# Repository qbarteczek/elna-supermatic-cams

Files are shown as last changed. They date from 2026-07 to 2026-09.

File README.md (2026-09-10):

# Generator krzywek Elna Supermatic / Elna Supermatic Cam Studio

*Dokument dwujęzyczny — polski niżej, English below. / Bilingual document — Polish first, English below.*

---

> [!TIP]
> ### 🌐 [URUCHOM GENERATOR KRZYWEK ONLINE (BEZ INSTALOWANIA PROGRAMÓW)](https://qbarteczek.github.io/elna-supermatic-cams/)
> **Dla każdego użytkownika maszyny:** wybierz dowolną krzywkę z katalogu 34 wzorów lub zaprojektuj własny ścieg w edytorze 18-krokowym, zobacz dysk w 3D oraz wirtualne przeszycie na tkaninie i pobierz gotowy plik `.stl` do druku 3D jednym kliknięciem (0.01 s)!
> 
> *English: [CLICK HERE TO LAUNCH THE 3D CAM GENERATOR IN BROWSER (NO SOFTWARE NEEDED)](https://qbarteczek.github.io/elna-supermatic-cams/)*

---

## PL

Otwarta biblioteka i interaktywny **generator krzywek ściegowych (cam discs)** do szwajcarskich maszyn **Elna Supermatic**, **Elna SU** i modeli pokrewnych. 

W odróżnieniu od maszyn ze stałymi bębnami wielościegowymi, Elna wykorzystuje pojedyncze, wymienne dyski montowane na obrotowym trzpieniu maszyny. Projekt łączy dokładne pomiary fizycznych dysków fabrycznych i skanów STL z parametrycznym generatorem 3D działającym w 100% w przeglądarce internetowej oraz w programie OpenSCAD.

### 🚀 Szybki start: 3 Sposoby korzystania z generatora

1. **🌐 Interaktywna aplikacja Webowa Online ([https://qbarteczek.github.io/elna-supermatic-cams/](https://qbarteczek.github.io/elna-supermatic-cams/)):**
   - **Podgląd 3D w czasie rzeczywistym (WebGL / Three.js):** natychmiastowe obracanie i oglądanie dysku z ząbkami wieńca, stożkowym otworem montażowym i gniazdem zabieraka.
   - **Bezpośrednie pobieranie STL:** klikasz *„💾 Pobierz STL do druku 3D”* i w 0.01 sekundy otrzymujesz szczelny (watertight / 2-manifold) plik `.stl` do wrzucenia do slicera (Bambu Studio, OrcaSlicer, PrusaSlicer, Cura).
   - **Wirtualne przeszycie na tkaninie:** podgląd nici na żywo dla 18 kroków pełnego obrotu dysku z animacją pracy maszyny.
   - **Katalog 34 krzywek fabrycznych:** 1-klikowe ładowanie profili od 01 do 34.
   - **Edytor 18-krokowy:** pełna swoboda tworzenia własnych ściegów z narzędziami generowania sinusoidy, schodków, zygzaka czy muszelki.
   - **Działanie offline:** wystarczy kliknąć dwukrotnie plik `Uruchom_Generator.bat` w głównym katalogu projektu.
2. **Panel okienkowy OpenSCAD Customizer GUI** ([`tools/openscad/elna_cam_generator.scad`](tools/openscad/elna_cam_generator.scad)): rozwijane menu wyboru krzywek 01–34 lub tryb Custom w oknie OpenSCAD (Window -> Customizer).
3. **Wiersz poleceń Python** ([`tools/generate_cam.py`](tools/generate_cam.py)): zautomatyzowane generowanie modeli `.scad` i profili `.json`.

Szczegółowa instrukcja obsługi: [`docs/GENERATOR.md`](docs/GENERATOR.md) (PL) oraz [`docs/GENERATOR.en.md`](docs/GENERATOR.en.md) (EN).

---

### ⚙️ Wymiary techniczne i pomiary nominalne

Dyski generowane są na podstawie ścisłych wymiarów nominalnych:
- **Średnica zewnętrzna:** 43.64 mm (promień maks. 21.82 mm)
- **Wysokość całkowita:** 7.31 mm (korpus 7.00 mm + oznaczenia 0.31 mm)
- **Wieniec roboczy:** wysokość 4.50 mm, promień bazowy 18.55 mm, promień maks. 21.82 mm
- **Skok krzywki (Throw):** 3.27 mm (przekłada się na szerokość ściegu 0–4 mm)
- **Otwór osi:** fi 16.50 mm (r=8.25 mm) z dolnym podtoczeniem fi 19.00 mm (h=1.5 mm) i stożkiem 1.5 mm
- **Gniazdo zabieraka napędowego:** szerokość 3.0 mm, długość 4.1 mm, głębokość 5.5 mm

---

### 📚 Pełny indeks 34 krzywek w repozytorium

| Numer | Nazwa ściegu | Status | Wieniec | Zastosowanie |
|:---:|:---|:---:|:---:|:---|
| **01** | Elastic multi-step | candidate | smooth | Ścieg elastyczny wielostopniowy |
| **02** | Serpentine | candidate | smooth | Serpentyna / płynna fala |
| **03** | Zigzag reference | reference STL/SCAD | stepped | Zygzak standardowy referencyjny |
| **04** | Long scallop | candidate | smooth | Długa muszelka ozdobna |
| **05** | Scallop | candidate | smooth | Klasyczna muszelka brzegowa |
| **06** | Wide zigzag | candidate | stepped | Zygzak szeroki dwustopniowy |
| **07** | Decorative zigzag | candidate | smooth | Zygzak ozdobny ząbkowany |
| **08** | Slanted bars | candidate | stepped | Paski skośne / jodełka |
| **09** | W stitch | candidate | stepped | Ścieg w kształcie litery W |
| **10** | Blind hem | candidate | stepped | Ścieg kryty do podszywania |
| **11** | Arrows | candidate | smooth | Strzałki geometryczne |
| **12** | Spindle | candidate | smooth | Wrzeciono / kropla satynowa |
| **13** | Source profile 13 | source-profile | smooth | Profil bazowy z projektu źródłowego |
| **14** | Loop wave | candidate | smooth | Pętle faliste |
| **15** | Triangle | candidate | stepped | Trójkąty ostre |
| **16** | Source profile 16 | source-profile | smooth | Profil bazowy z projektu źródłowego |
| **17** | Round pulses | candidate | stepped | Impulsy zaokrąglone |
| **18** | Deep scallop | candidate | smooth | Głęboka muszelka satynowa |
| **19** | Dense zigzag | candidate | stepped | Zygzak gęsty |
| **20** | Source profile 20 | source-profile | stepped | Profil bazowy z projektu źródłowego |
| **21** | Stair zigzag | candidate | smooth | Zygzak schodkowy |
| **22** | Small lobes | candidate | smooth | Drobne łuski |
| **23** | Sharp triangles | candidate | smooth | Trójkąty wyostrzone |
| **24** | Small scallop | candidate | smooth | Drobna muszelka |
| **25** | Large sine wave | candidate | smooth | Duża sinusoida |
| **26** | Wave variant | candidate | smooth | Wariant fali symetrycznej |
| **27** | Irregular pulse | candidate | stepped | Impuls nieregularny |
| **28** | Vertical ticks | candidate | stepped | Pionowe kreski / grzebyk |
| **29** | Comb alternate | candidate | smooth | Grzebyk naprzemienny |
| **30** | Uneven wave | candidate | smooth | Fala asymetryczna |
| **31** | Block sawtooth | candidate | stepped | Zęby piły blokowe |
| **32** | Slanted bars | candidate | smooth | Paski skośne gładkie |
| **33** | Source profile 33 | source-profile | smooth | Profil bazowy z projektu źródłowego |
| **34** | Extra decorative | candidate | smooth | Złożony ścieg dekoracyjny |

---

### 🖨️ Zalecenia dotyczące druku 3D (FDM)

- **Materiał:** **PETG** (zalecany ze względu na niski współczynnik tarcia i odporność na pękanie) lub **PLA / PLA+**.
- **Wysokość warstwy:** `0.12 mm` lub `0.16 mm` dla idealnie gładkiego profilu krzywki.
- **Wypełnienie / Ścianki:** 4–5 obrysów lub 100% wypełnienia (dysk musi być sztywny).
- **Pozycja na stole:** Płasko, spodem do stołu (brak podpór).

---

### 📁 Struktura projektu

```text
├── index.html                           # Główna aplikacja generatora online (GitHub Pages)
├── Uruchom_Generator.bat                # 1-klikowy launcher pod Windows
├── docs/
│   ├── GENERATOR.md                     # Instrukcja obsługi generatora (PL)
│   ├── GENERATOR.en.md                  # Generator user guide (EN)
│   ├── DIMENSIONS_FROM_UPLOADED_FILES.md# Raport z pomiarów referencyjnych
│   └── MEASURED_PARAMETRIC_INDEX.md     # Indeks krzywek parametrycznych
├── models/
│   ├── measured_parametric_single_v1/   # Gotowe modele OpenSCAD dla krzywek 01–34
│   │   ├── _elna_measured_common.scad   # Główna baza wymiarowa
│   │   ├── cam_01.scad ... cam_34.scad  # Pliki modeli
│   │   └── profiles/                    # Profile JSON dla wszystkich 34 krzywek
├── tools/
│   ├── build_index_html.py              # Skrypt kompilujący index.html z presetami
│   ├── generate_cam.py                  # Narzędzie CLI do generowania SCAD i JSON
│   ├── openscad/
│   │   └── elna_cam_generator.scad      # Generator OpenSCAD z panelem Customizer
│   └── generator/
│       └── index.html                   # Kopia aplikacji webowej do pracy offline
└── LICENSE                              # Licencja GPL-3.0
```

---

## EN

Open library and interactive **stitch cam disc generator** for the legendary Swiss sewing machines **Elna Supermatic**, **Elna SU**, and related models.

### 🌐 [LAUNCH 3D CAM GENERATOR IN BROWSER](https://qbarteczek.github.io/elna-supermatic-cams/)

- **No installation needed:** Runs in your browser with real-time WebGL 3D preview and instant 0.01 s binary STL download.
- **Full library of 34 factory cam profiles:** 1-click loading with live fabric stitch simulation.
- **18-Step Custom Designer:** Create completely custom stitch designs.
- **OpenSCAD GUI Customizer:** Available in `tools/openscad/elna_cam_generator.scad`.
- **3D Print Ready:** Watertight 2-manifold STL models tailored for PETG/PLA printing with zero supports.

Read the complete English guide in [`docs/GENERATOR.en.md`](docs/GENERATOR.en.md).

---

## Licencja / License

Projekt objęty licencją **GPL-3.0-or-later**.
Zachowaj informacje o autorach kodu bazowego i projektów źródłowych (ln-komandur/elna-cam-discs).

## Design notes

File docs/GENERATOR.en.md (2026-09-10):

# Elna Supermatic Cam Generator User Guide

This repository features a built-in, versatile system for generating factory and custom stitch cam discs for the iconic Swiss sewing machines **Elna Supermatic**, **Elna SU**, and related models.

The generator includes a full catalog of **34 pre-configured cam profiles** (utility stitches, elastic stretch stitches, decorative scallops, waves, and geometric patterns) and an interactive 18-step designer for creating brand new stitches.

---

## 🌐 In-Browser Online Generator (Recommended!)

> [!TIP]
> **No installation required (no OpenSCAD, Python, or compiler needed)!**
> Access the generator directly in your browser:
> 👉 **[https://qbarteczek.github.io/elna-supermatic-cams/](https://qbarteczek.github.io/elna-supermatic-cams/)**

The application runs 100% locally in your web browser (desktop, tablet, or smartphone) and produces a production-ready, watertight binary `.stl` file in a fraction of a second (0.01 s).

---

## 3 Ways to Use the Generator

### Method 1: Web App Online / Offline (Easiest for Everyone)

1. **How to Launch:**
   * **Online (recommended):** Visit [https://qbarteczek.github.io/elna-supermatic-cams/](https://qbarteczek.github.io/elna-supermatic-cams/)
   * **Offline on PC:** Double click `Uruchom_Generator.bat` in the project root folder (or open `index.html` in any modern web browser).
2. **Features:**
   * **Real-Time 3D Cam Disc Viewer (WebGL / Three.js):** rotate, zoom, and inspect the real cam disc geometry with lower functional lobe, central bore, counterbore, driving pin slot, and embossed top markings.
   * **Virtual Fabric Seam Simulation:** live simulation showing what stitch pattern is formed on fabric over the 18 steps of the cam rotation. Click *„▶ Start Machine”* to watch the animated sewing action!
   * **Catalog of 34 Cams:** 1-click loading of any factory cam (01 through 34) with live search and wave previews.
   * **18-Step Profile Designer:** interactive height sliders for each needle position (`L`, `CL`, `C`, `CR`, `R` or continuous 0.0 – 3.0), wave generator tools (sine, zigzag, stairs, blind hem, invert).
   * **Custom Markings:** set custom cam numbers (e.g. `03`, `42`, `MY`) embossed in 3D on the disc surface.
3. **Download 3D Print File:**
   * Click the green button **„💾 Download STL for 3D Printing”** – in 0.01 s you get a watertight (2-manifold) `elna_cam_XX.stl` file ready for slicing in Bambu Studio, OrcaSlicer, PrusaSlicer, or Cura.
   * You can also download the OpenSCAD `.scad` code or export/import `.json` profiles.

---

### Method 2: In OpenSCAD (Customizer GUI)

For users who prefer working inside OpenSCAD:
1. Install [OpenSCAD](https://openscad.org/) (version 2021.01+).
2. Open [`tools/openscad/elna_cam_generator.scad`](../tools/openscad/elna_cam_generator.scad).
3. Enable the GUI parameter panel: **Window -> Customizer** (or uncheck *Hide Customizer*).
4. Select a preset from `PRESET` (`01` to `34`) or select `CUSTOM` to adjust the 18 step sliders.
5. Press **F5** (preview) or **F6** (render), then **F7** (Export as STL).

---

### Method 3: Python Command Line (`tools/generate_cam.py`)

CLI script for automated generation of `.scad` files and `.json` profiles:
```bash
# Generate a SCAD model from 18 values:
python tools/generate_cam.py --cam 03 --values 0,3,0,3,0,3,0,3,0,3,0,3,0,3,0,3,0,3 --mode stepped --out models/generated/cam_03.scad

# Generate from an existing JSON profile:
python tools/generate_cam.py --profile models/measured_parametric_single_v1/profiles/cam_10_profile.json --out output.scad
```

---

## Cam Catalog Overview (01–34)

| Cam | Stitch Name | Status | Cam Surface | Application |
|:---:|:---|:---:|:---:|:---|
| **01** | Elastic multi-step | candidate | smooth | Multi-step stretch stitch |
| **02** | Serpentine | candidate | smooth | Smooth wave / serpentine |
| **03** | Zigzag reference | uploaded-stl/reference | stepped | Standard reference zigzag |
| **04** | Long scallop | candidate | smooth | Extended decorative scallop |
| **05** | Scallop | candidate | smooth | Classic edge scallop |
| **06** | Wide zigzag | candidate | stepped | 2-step wide zigzag |
| **07** | Decorative zigzag | candidate | smooth | Saw-tooth decorative zigzag |
| **08** | Slanted bars | candidate | stepped | Slanted bar chevron |
| **09** | W stitch | candidate | stepped | W-shaped stitch |
| **10** | Blind hem | candidate | stepped | Blind hem hemming stitch |
| **11** | Arrows | candidate | smooth | Geometric arrowheads |
| **12** | Spindle | candidate | smooth | Satin spindle / teardrop |
| **13** | Source profile 13 | source-profile | smooth | Profile from base project |
| **14** | Loop wave | candidate | smooth | Looped waves |
| **15** | Triangle | candidate | stepped | Sharp triangles |
| **16** | Source profile 16 | source-profile | smooth | Profile from base project |
| **17** | Round pulses | candidate | stepped | Rounded pulse waves |
| **18** | Deep scallop | candidate | smooth | Deep satin scallop |
| **19** | Dense zigzag | candidate | stepped | Dense zigzag |
| **20** | Source profile 20 | source-profile | stepped | Profile from base project |
| **21** | Stair zigzag | candidate | smooth | Stepped staircase zigzag |
| **22** | Small lobes | candidate | smooth | Small rounded lobes |
| **23** | Sharp triangles | candidate | smooth | Sharpened triangle pattern |
| **24** | Small scallop | candidate | smooth | Fine edge scallop |
| **25** | Large sine wave | candidate | smooth | Large amplitude sine wave |
| **26** | Wave variant | candidate | smooth | Symmetric wave variation |
| **27** | Irregular pulse | candidate | stepped | Asymmetric pulse sequence |
| **28** | Vertical ticks | candidate | stepped | Vertical comb ticks |
| **29** | Comb alternate | candidate | smooth | Alternating comb pattern |
| **30** | Uneven wave | candidate | smooth | Asymmetric wave |
| **31** | Block sawtooth | candidate | stepped | Block sawtooth |
| **32** | Slanted bars | candidate | smooth | Smooth slanted bars |
| **33** | Source profile 33 | source-profile | smooth | Profile from base project |
| **34** | Extra decorative | candidate | smooth | Complex decorative stitch |

---

## ⚙️ Technical Specifications & Dimensions

All models are built upon measured dimensions from physical original cam discs and high-precision reference STL scans:

| Feature | Nominal Value | Machine Function |
|---|:---:|---|
| **Outer Diameter ($D_{max}$)** | **43.64 mm** | Clearance in cam compartment |
| **Total Height ($H_{total}$)** | **7.31 mm** | Main body (7.0 mm) + embossed badges (0.31 mm) |
| **Base Cam Radius ($R_{base}$)** | **18.55 mm** | Far-left needle position (throw = 0 mm) |
| **Max Cam Radius ($R_{max}$)** | **21.82 mm** | Far-right needle position (throw = 4 mm) |
| **Functional Lobe Height ($H_{lobe}$)** | **4.50 mm** | Lower portion engaging cam follower |
| **Cam Throw** | **3.27 mm** | Needle bar lever deflection range |
| **Shaft Bore Diameter ($D_{hole}$)** | **16.50 mm** | Spindle mount fit ($r = 8.25$ mm) |
| **Lower Counterbore Diameter ($D_{counterbore}$)** | **19.00 mm** | Spindle shoulder recess ($r = 9.50$ mm, $h = 1.5$ mm) |
| **Conical Lead-in ($H_{cone}$)** | **1.50 mm** | Tapered transition from 19 mm to 16.5 mm |
| **Drive Pin Slot** | **3.0 × 4.1 mm** | Locating slot for driving pin ($d = 5.5$ mm) |

---

## 🖨️ 3D Printing Recommendations (FDM)

1. **Filament Choice:**
   * **PETG (Recommended):** High wear resistance against metal cam followers, good flexibility, non-brittle.
   * **PLA / PLA+:** Excellent dimensional fidelity and stiffness, fine for domestic stitching.
   * **ABS / ASA / Nylon:** Optional for advanced users.
2. **Slicer Settings:**
   * **Layer Height:** `0.12 mm` or `0.16 mm` for smooth cam profiles without layer stepping.
   * **Perimeters / Walls:** `4` to `5` loops.
   * **Infill:** `40%–100%` (rigid disc prevents deflection under follower spring pressure).
   * **Orientation:** Flat on build plate, bottom face down.
   * **Supports:** **None** – designed to print 100% support-free.

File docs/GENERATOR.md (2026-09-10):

# Instrukcja obsługi generatora krzywek Elna Supermatic

Projekt zawiera wbudowany, uniwersalny system generowania własnych oraz fabrycznych dysków ściegowych (krzywek wymiennych) do kultowych szwajcarskich maszyn do szycia **Elna Supermatic**, **Elna SU** i modeli pokrewnych.

Dostępny jest pełny katalog **34 gotowych profili krzywek** (ściegi użytkowe, elastyczne, dekoracyjne muszelki, fale i wzory geometryczne) oraz możliwość projektowania zupełnie nowych, autorskich ściegów w edytorze 18-krokowym.

---

## 🌐 Generator Online w Przeglądarce (Zalecany dla każdego użytkownika!)

> [!TIP]
> **Nie musisz instalować żadnego oprogramowania (w tym OpenSCAD ani Pythona)!**
> Wejdź bezpośrednio na stronę generatora:
> 👉 **[https://qbarteczek.github.io/elna-supermatic-cams/](https://qbarteczek.github.io/elna-supermatic-cams/)**

Aplikacja działa w 100% w przeglądarce internetowej (na komputerze, tablecie i smartfonie) i umożliwia wygenerowanie oraz natychmiastowe pobranie gotowego pliku `.stl` do druku 3D w ułamku sekundy (0.01 s).

---

## 3 Sposoby korzystania z generatora

### Sposób 1: Aplikacja Webowa Online / Lokalna (Najwygodniejszy dla każdego!)

1. **Uruchomienie:**
   * **Online (zalecane):** Otwórz [https://qbarteczek.github.io/elna-supermatic-cams/](https://qbarteczek.github.io/elna-supermatic-cams/)
   * **Lokalnie na komputerze (bez internetu):** Kliknij dwukrotnie plik `Uruchom_Generator.bat` w głównym katalogu projektu (lub po prostu otwórz plik `index.html` w ulubionej przeglądarce).
2. **Możliwości studia projektowego:**
   * **Interaktywny podgląd 3D dysku (WebGL / Three.js):** obracaj myszką, przybliżaj i oglądaj rzeczywisty dysk krzywki z wieńcem funkcyjnym, stożkowym otworem montażowym, wpustem zabieraka i sygnaturami górnymi.
   * **Wirtualna symulacja ściegu na tkaninie:** dynamiczny podgląd przeszycia nici na materiale dla 18 kroków pełnego obrotu dysku. Przycisk *„▶ Uruchom maszynę”* uruchamia realistyczną animację pracy igły i posuwu materiału.
   * **Katalog 34 krzywek Elna:** błyskawiczny wybór fabrycznych dysków (od 01 do 34) z podglądem fali i wyszukiwarką.
   * **Edytor 18-krokowy:** interaktywne słupki z regulacją odchylenia igły (pozycje `L`, `CL`, `C`, `CR`, `R` lub płynne wartości 0.0 – 3.0), narzędzia generowania fal (sinusoida, zygzak, schodki, trójskok, ścieg kryty, inwersja).
   * **Dostosowanie oznaczeń:** wpisz własny numer dysku wytłaczany na tarczy (np. `03`, `42`, `MY`) oraz wybierz rodzaj piktogramu.
3. **Pobranie pliku do druku 3D:**
   * Kliknij zielony przycisk **„💾 Pobierz STL do druku 3D”** – w ułamku sekundy otrzymujesz gotowy, w 100% szczelny (watertight / 2-manifold) plik `elna_cam_XX.stl`, który możesz bezpośrednio otworzyć w Bambu Studio, OrcaSlicer, PrusaSlicer czy Cura!
   * Możesz także pobrać kod źródłowy `.scad` lub wyeksportować/zaimportować profil `.json`.

---

### Sposób 2: W programie OpenSCAD (Panel Customizer GUI)

Dla użytkowników preferujących pracę bezpośrednio w programie OpenSCAD:
1. Zainstaluj darmowy program [OpenSCAD](https://openscad.org/) (wersja 2021.01 lub nowsza).
2. Otwórz plik [`tools/openscad/elna_cam_generator.scad`](../tools/openscad/elna_cam_generator.scad).
3. W górnym menu OpenSCAD włącz panel parametrów: **Window -> Customizer** (lub odznacz *Hide Customizer*).
4. Wybierz gotową krzywkę z listy `PRESET` (`01` do `34`) lub wybierz `CUSTOM` i ustaw własne wartości 18 kroków za pomocą suwaków.
5. Wciśnij klawisz **F5** (szybki podgląd) lub **F6** (pełny render), a po zakończeniu obliczeń **F7** (Export as STL).

---

### Sposób 3: Wiersz poleceń Python (`tools/generate_cam.py`)

Skrypt CLI do zautomatyzowanego generowania modeli `.scad` i profili `.json`:
```bash
# Wygenerowanie modelu SCAD z zadanymi 18 wartościami:
python tools/generate_cam.py --cam 03 --values 0,3,0,3,0,3,0,3,0,3,0,3,0,3,0,3,0,3 --mode stepped --out models/generated/cam_03.scad

# Wygenerowanie modelu na podstawie istniejącego pliku JSON profilu:
python tools/generate_cam.py --profile models/measured_parametric_single_v1/profiles/cam_10_profile.json --out output.scad
```

---

## Pełny wykaz profili krzywek w katalogu (01–34)

| Numer | Nazwa ściegu | Status | Typ wieńca | Zastosowanie |
|:---:|:---|:---:|:---:|:---|
| **01** | Elastic multi-step | candidate | smooth | Ścieg elastyczny wielostopniowy |
| **02** | Serpentine | candidate | smooth | Serpentyna / płynna fala |
| **03** | Zigzag reference | uploaded-stl/reference | stepped | Zygzak standardowy referencyjny |
| **04** | Long scallop | candidate | smooth | Długa muszelka ozdobna |
| **05** | Scallop | candidate | smooth | Klasyczna muszelka brzegowa |
| **06** | Wide zigzag | candidate | stepped | Zygzak szeroki dwustopniowy |
| **07** | Decorative zigzag | candidate | smooth | Zygzak ozdobny ząbkowany |
| **08** | Slanted bars | candidate | stepped | Paski skośne / jodełka |
| **09** | W stitch | candidate | stepped | Ścieg w kształcie litery W |
| **10** | Blind hem | candidate | stepped | Ścieg kryty do podszywania |
| **11** | Arrows | candidate | smooth | Strzałki geometryczne |
| **12** | Spindle | candidate | smooth | Wrzeciono / kropla satynowa |
| **13** | Source profile 13 | source-profile | smooth | Profil bazowy z projektu źródłowego |
| **14** | Loop wave | candidate | smooth | Pętle faliste |
| **15** | Triangle | candidate | stepped | Trójkąty ostre |
| **16** | Source profile 16 | source-profile | smooth | Profil bazowy z projektu źródłowego |
| **17** | Round pulses | candidate | stepped | Impulsy zaokrąglone |
| **18** | Deep scallop | candidate | smooth | Głęboka muszelka satynowa |
| **19** | Dense zigzag | candidate | stepped | Zygzak gęsty |
| **20** | Source profile 20 | source-profile | stepped | Profil bazowy z projektu źródłowego |
| **21** | Stair zigzag | candidate | smooth | Zygzak schodkowy |
| **22** | Small lobes | candidate | smooth | Drobne łuski |
| **23** | Sharp triangles | candidate | smooth | Trójkąty wyostrzone |
| **24** | Small scallop | candidate | smooth | Drobna muszelka |
| **25** | Large sine wave | candidate | smooth | Duża sinusoida |
| **26** | Wave variant | candidate | smooth | Wariant fali symetrycznej |
| **27** | Irregular pulse | candidate | stepped | Impuls nieregularny |
| **28** | Vertical ticks | candidate | stepped | Pionowe kreski / grzebyk |
| **29** | Comb alternate | candidate | smooth | Grzebyk naprzemienny |
| **30** | Uneven wave | candidate | smooth | Fala asymetryczna |
| **31** | Block sawtooth | candidate | stepped | Zęby piły blokowe |
| **32** | Slanted bars | candidate | smooth | Paski skośne gładkie |
| **33** | Source profile 33 | source-profile | smooth | Profil bazowy z projektu źródłowego |
| **34** | Extra decorative | candidate | smooth | Złożony ścieg dekoracyjny |

---

## ⚙️ Wymiary techniczne dysku Elna Supermatic

Wszystkie modele w generatorze bazują na dokładnych pomiarach oryginalnych dysków i referencyjnych skanów STL:

| Parametr konstrukcyjny | Wartość nominalna | Znaczenie w maszynie |
|---|:---:|---|
| **Średnica zewnętrzna ($D_{max}$)** | **43.64 mm** | Maksymalny gabaryt w gnieździe krzywek |
| **Wysokość całkowita ($H_{total}$)** | **7.31 mm** | Grubość korpusu (7.0 mm) + oznaczenia (0.31 mm) |
| **Promień bazowy wieńca ($R_{base}$)** | **18.55 mm** | Skrajna lewa pozycja igły (rzut = 0 mm) |
| **Promień maksymalny wieńca ($R_{max}$)** | **21.82 mm** | Skrajna prawa pozycja igły (rzut = 4 mm) |
| **Wysokość wieńca roboczego ($H_{lobe}$)** | **4.50 mm** | Dolna część współpracująca z popychaczem igielnicy |
| **Skok krzywki (Throw)** | **3.27 mm** | Zakres ruchu dźwigni igielnicy |
| **Średnica otworu osi ($D_{hole}$)** | **16.50 mm** | Otwór pasowany na trzpień napędowy (r=8.25 mm) |
| **Średnica dolnego podtoczenia ($D_{counterbore}$)** | **19.00 mm** | Pogłębienie na kołnierz osi (r=9.50 mm, h=1.5 mm) |
| **Stożek wprowadzający ($H_{cone}$)** | **1.50 mm** | Przejście stożkowe r=9.5 -> r=8.25 mm |
| **Wymiary gniazda zabieraka** | **3.0 × 4.1 mm** | Wpust na kołek napędowy (głębokość 5.5 mm) |

---

## 🖨️ Wskazówki dotyczące druku 3D (FDM)

1. **Materiał:**
   * **PETG (Zalecany):** Zapewnia doskonałą odporność na ścieranie przy tarciu metalowego popychacza, elastyczność i brak kruchości.
   * **PLA / PLA+:** Bardzo dobra dokładność wymiarowa i sztywność, odpowiednia do domowych zastosowań.
   * **ABS / ASA / Nylon:** Opcjonalnie dla zaawansowanych użytkowników.
2. **Ustawienia slicera:**
   * **Wysokość warstwy:** `0.12 mm` lub `0.16 mm` (zapewnia gładką krawędź krzywki bez schodkowania warstw).
   * **Obrysy (Perimeters / Walls):** `4` do `5` obrysów.
   * **Wypełnienie (Infill):** `40%–100%` (krzywka powinna być sztywna i solidna).
   * **Orientacja na stole:** Płasko, podstawą (dolną stroną z podtoczeniem) do stołu roboczego.
   * **Podpory:** **Brak** – model został zaprojektowany w sposób samonośny bez potrzeby stosowania podpór.
3. **Przygotowanie po wydruku:**
   * Oczyść ewentualne nitki (stringing) i sprawdź suwmiarką otwór centralny (16.5 mm). W razie potrzeby delikatnie przeszlifuj papierem ściernym gradacji 400–600 krawędź roboczą wieńca, aby zapewnić aksamitną pracę igielnicy.

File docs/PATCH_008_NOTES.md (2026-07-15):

# Patch 008 — measured parametric base

> **Note:** This document is kept for historical reference.
> The current project status and design rules are described in the main [README.md](../README.md).

---

This patch fixes the earlier mistake: it does not try to edit the frozen mesh SCAD.

Instead it builds a clean parametric OpenSCAD base using the dimensions read from the
uploaded STL/SCAD files.

## Rule

Preserve:
- measured outer size,
- total height,
- upper round body,
- central hole,
- lower counterbore/cone,
- transport slot,
- top style layout.

Change only:
- lower functional cam edge,
- number,
- stitch pictogram.

## Folder

```text
models/measured_parametric_single_v1/
```

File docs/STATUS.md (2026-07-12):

# Project status

## Stable base

The current stable direction is:

```text
models/measured_parametric_single_v1/
```

This base is dimensioned from the uploaded STL/SCAD reference files.

## Reliability levels

### `uploaded-stl/scad-reference`

The cam is based on the uploaded STL/SCAD reference.

Currently:

- 03

### `source-profile`

The cam uses a known 18-position OpenSCAD profile.

Currently:

- 13
- 16
- 20
- 33

### `candidate`

The cam uses the measured base, but the functional outer profile is not yet verified from a physical disc.

Currently:

- remaining generated cams 01–34

## Do not treat candidates as final

Candidate profiles are useful for visual comparison and early development, but should not be sold or described as factory-accurate until verified.

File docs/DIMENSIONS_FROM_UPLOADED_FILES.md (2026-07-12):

# Dimensions read from uploaded STL/SCAD

## Parsed STL / SCAD measurements

- SCAD object1Min: `[45.388, 55.498, 0.0]`
- SCAD object1Max: `[89.02, 97.731, 7.308]`
- SCAD extents: `[43.632, 42.233, 7.308] mm`

### ElnaSupermaticZizagCamWhole.stl

- vertices: `40482`
- min: `[45.388, 55.498, 0.0]`
- max: `[89.02, 97.731, 7.308]`
- extents: `[43.632, 42.233, 7.308]` mm
- bbox center: `[67.204, 76.615, 3.654]`
- max radius from bbox center: `22.043 mm`

### ElnaSupermaticZizagCam3NoBottomRing.stl

- vertices: `27402`
- min: `[50.725, 8.941, 0.0]`
- max: `[94.361, 51.742, 6.048]`
- extents: `[43.636, 42.801, 6.048]` mm
- bbox center: `[72.543, 30.342, 3.024]`
- max radius from bbox center: `22.044 mm`

## Dimensions used in patch 008

| Parameter | Value |
|---|---:|
| `overall_diameter_mm` | 43.640 mm |
| `overall_radius_mm` | 21.820 mm |
| `total_height_mm` | 7.308 mm |
| `body_top_height_mm` | 6.999 mm |
| `label_height_mm` | 0.309 mm |
| `lower_cam_lobe_height_mm` | 4.499 mm |
| `upper_round_body_radius_mm` | 18.550 mm |
| `functional_lobe_min_radius_mm` | 18.550 mm |
| `functional_lobe_max_radius_mm` | 21.820 mm |
| `functional_lobe_throw_mm` | 3.270 mm |
| `center_hole_radius_mm` | 8.250 mm |
| `center_counterbore_radius_mm` | 9.500 mm |
| `center_counterbore_height_mm` | 1.500 mm |
| `center_cone_height_mm` | 1.500 mm |
| `transport_slot_width_mm` | 3.000 mm |
| `transport_slot_length_mm` | 4.100 mm |
| `transport_slot_depth_mm` | 5.500 mm |
| `transport_slot_gap_from_counterbore_mm` | 1.000 mm |

## Design rule used

The model preserves fixed dimensions and holes. Only these elements are variable:
- lower functional cam edge,
- number,
- stitch pictogram.

## Important

The candidate cams preserve the correct measured base and style, but their functional edge is not factory-verified until compared with a real top-down photo or STL scan.

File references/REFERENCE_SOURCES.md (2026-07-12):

# Reference sources

This patch primarily uses the user's uploaded files:
- ElnaSupermaticZizagCamWhole.stl
- ElnaSupermaticZizagCam3NoBottomRing.stl
- ElnaSupermaticZizagCamWhole.scad

Public references are used only for numbering and classification, not for claiming exact factory cam geometry.

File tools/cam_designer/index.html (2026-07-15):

🧵

# Elna Supermatic Cam Designer

Draw a stitch pattern → generate OpenSCAD cam disc

18 positions · 20° each GPL-3.0

## Stitch Pattern Editor

Click or drag to draw · Y = needle lateral position

✏️ Draw 〰️ Smooth Presets: Zigzag Straight Step Wave Satin Clear

3.0 2.0 1.0 0.0

0°40°80°120° 160°200°240°280° 320°360°

## Cam Profile Preview

Min radius

18.6mm

Max radius

21.8mm

Throw

3.3mm

Positions

18

## Stitch Pictogram Editor

Top disc icon (raised line)

Draw the stitch symbol that appears embossed on top of the cam disc.

✏️ Draw line 🧹 Erase 🗑️ Clear all ✨ Auto from stitch

Points snap to grid.
The line will be extruded 0.31mm
above the disc surface.

## Export

Cam number

Cam name

SCAD Type

Assembly Body Ring

⬇ JSON ⬇ SCAD ⬇ Both files

✓ Files downloaded!

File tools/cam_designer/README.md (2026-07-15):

# Elna Cam Designer

A browser-based tool for designing Elna Supermatic cam discs by drawing stitch patterns.

## How to use

### Online (GitHub Pages)
Open: **https://qbarteczek.github.io/elna-supermatic-cams/**

### Locally
Just open `index.html` in any modern browser — no installation, no server needed.

## Features

- **Stitch editor** — draw the needle position over 18 cam positions (0–360°)
  - Draw mode: click/drag to set exact values
  - Smooth mode: brush that blends neighbours
  - Presets: Zigzag, Straight, Step, Wave, Satin
- **Live cam preview** — SVG cam profile updates in real time
- **Pictogram editor** — draw the stitch icon that appears on top of the disc
  - Draw/erase tools
  - "Auto from stitch" — generates icon automatically from the stitch pattern
- **Export**
  - `cam_XX_profile.json` — profile data file for the repository
  - `cam_XX.scad` — ready-to-render OpenSCAD file (includes `_elna_measured_common.scad`)

## Value mapping

| Profile value | Needle position | Cam radius |
|---|---|---|
| `0.0` | Centre | 18.55 mm |
| `1.5` | Half-width | 20.19 mm |
| `3.0` | Full width | 21.82 mm |

18 positions × 20° each = one full stitch cycle (360°).

## Output files

After export, place the files in:

```
models/measured_parametric_single_v1/profiles/cam_XX_profile.json
models/measured_parametric_single_v1/cam_XX.scad
```

Then open `cam_XX.scad` in OpenSCAD and press **F6** to render.

> ⚠️ Exported cams have status `candidate` — always verify physically before use in a machine.

## License

GPL-3.0-or-later.

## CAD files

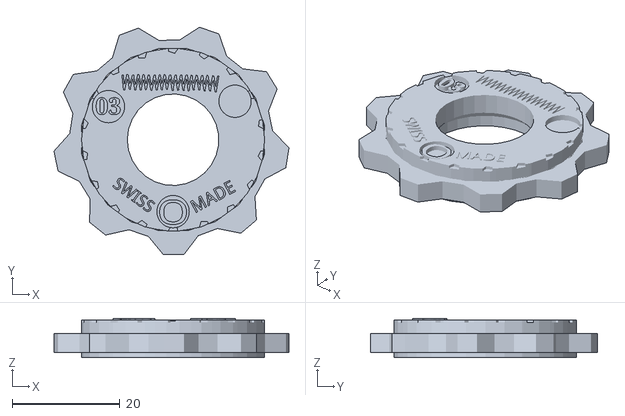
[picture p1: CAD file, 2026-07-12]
models/measured_parametric_single_v1/ElnaSupermaticZizagCamWhole.stl
43.6 x 42.2 x 7.31

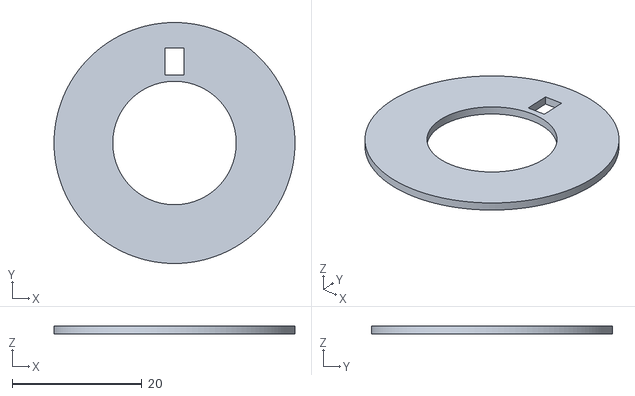
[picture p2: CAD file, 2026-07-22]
stls/universal_ring.stl
37.1 x 37.1 x 1.20

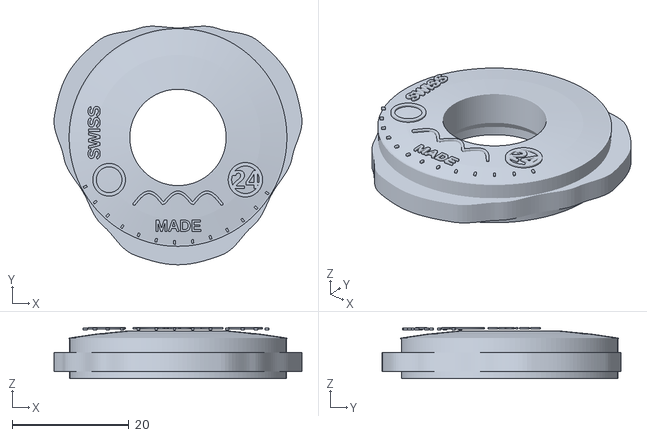
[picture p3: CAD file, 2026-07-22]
stls/cam_24_body.stl
42.5 x 40.9 x 8.81

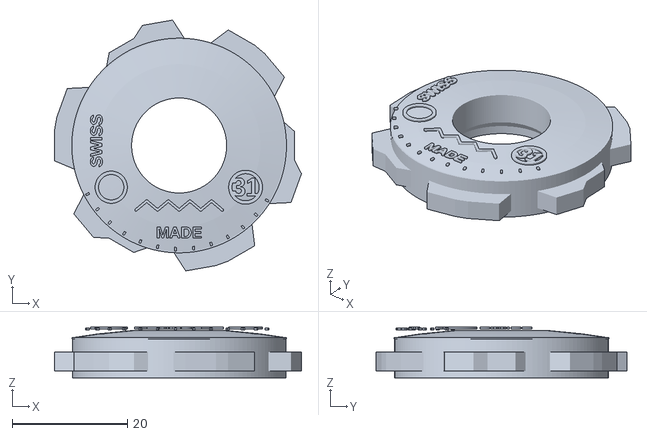
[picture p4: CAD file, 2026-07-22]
stls/cam_31_body.stl
42.9 x 43.6 x 8.81

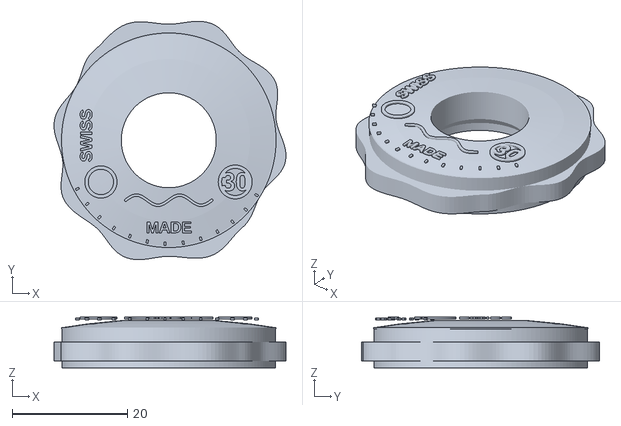
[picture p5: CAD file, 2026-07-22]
stls/cam_30_body.stl
40.3 x 41.4 x 8.81

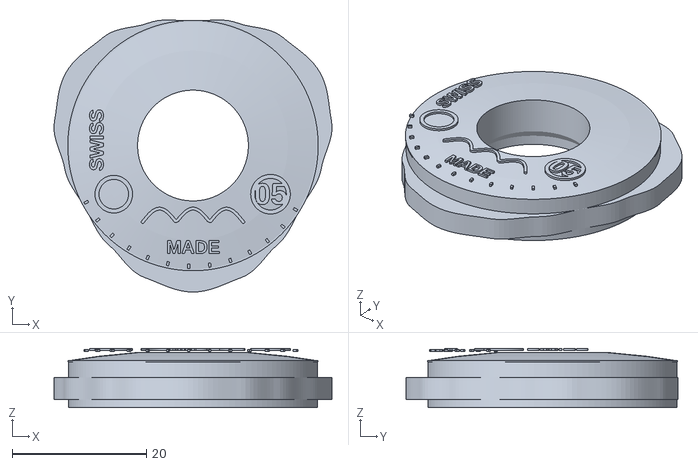
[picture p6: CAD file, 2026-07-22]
stls/cam_05_body.stl
41.4 x 40.5 x 8.81

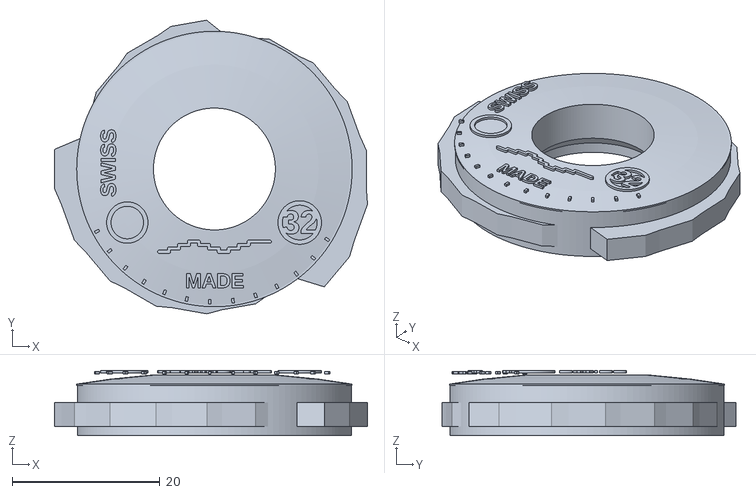
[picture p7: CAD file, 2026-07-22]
stls/cam_32_body.stl
42.4 x 39.8 x 8.81

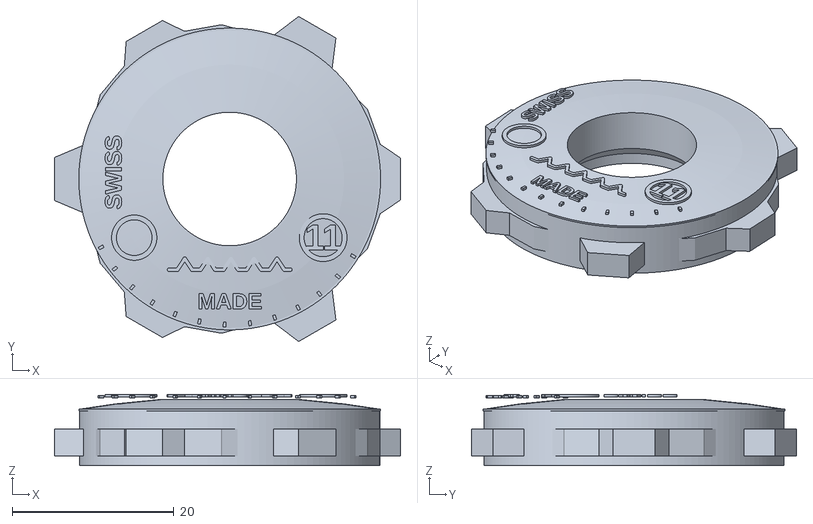
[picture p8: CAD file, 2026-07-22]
stls/cam_11_body.stl
42.8 x 40.2 x 8.81

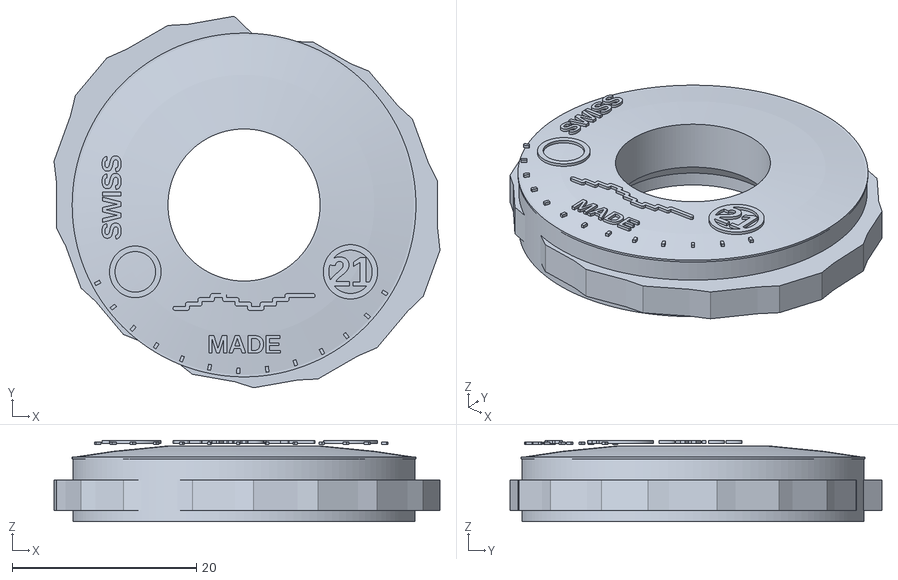
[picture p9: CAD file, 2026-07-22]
stls/cam_21_body.stl
41.9 x 40.3 x 8.81

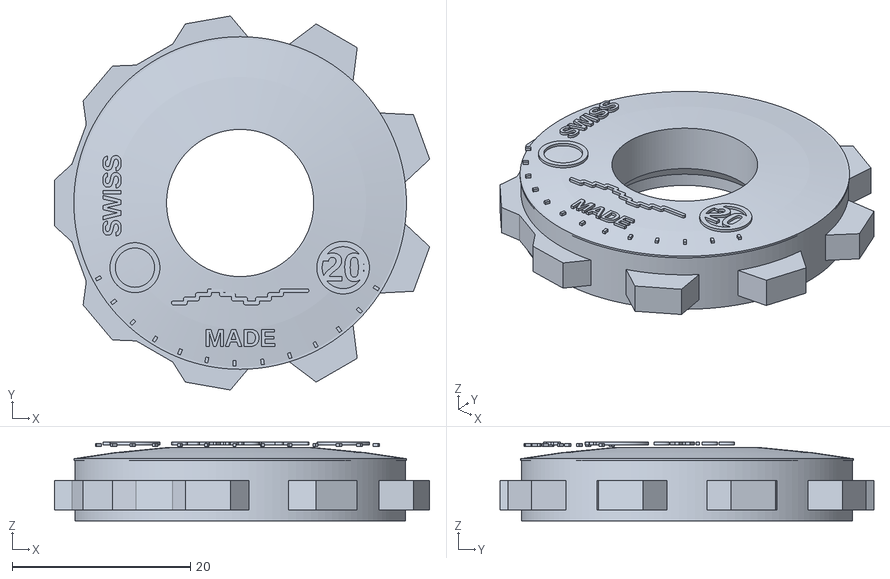
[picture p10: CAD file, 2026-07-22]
stls/cam_20_body.stl
42.1 x 41.9 x 8.81

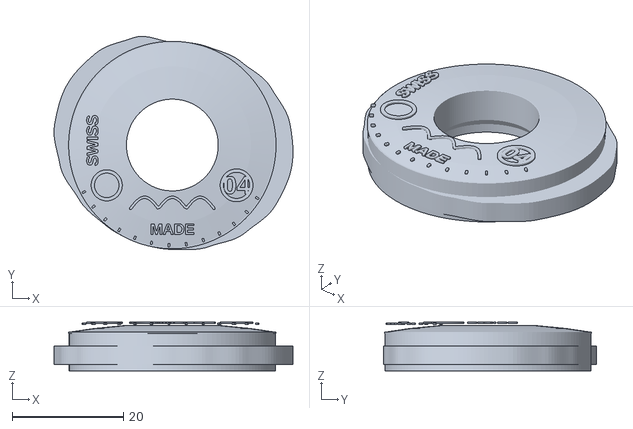
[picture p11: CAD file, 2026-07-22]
stls/cam_04_body.stl
43.0 x 38.3 x 8.81

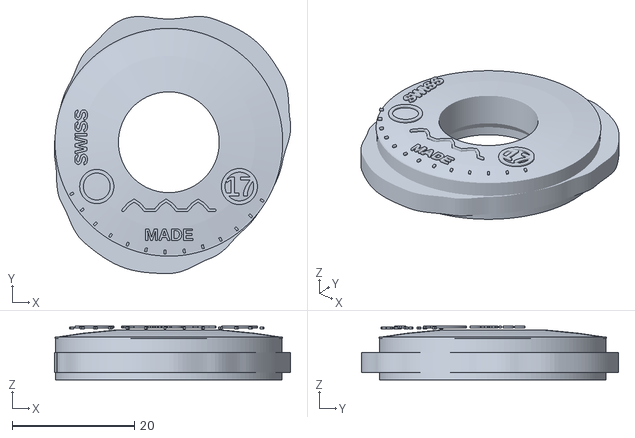
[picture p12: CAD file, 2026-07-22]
stls/cam_17_body.stl
38.7 x 42.1 x 8.81

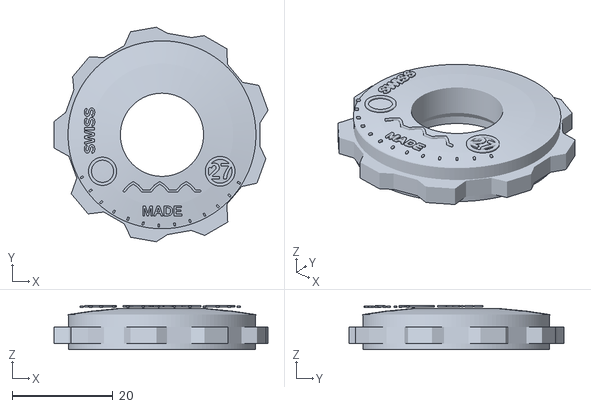
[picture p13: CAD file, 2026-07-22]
stls/cam_27_body.stl
42.5 x 42.6 x 8.81

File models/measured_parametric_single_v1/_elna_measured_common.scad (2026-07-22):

/*
  Elna Supermatic single cam — measured parametric base v2.

  Dimensions from uploaded STL/SCAD reference files:
    ElnaSupermaticZizagCamWhole.stl
    ElnaSupermaticZizagCam3NoBottomRing.stl
    ElnaSupermaticZizagCamWhole.scad

  v2 changes vs v1:
    - Bottom ring (rant) is a SEPARATE printable element (ring_only module).
    - Top surface is a gentle dome (~1.5 mm crown) instead of flat cylinder.
    - New module layout:
        base_body_no_ring()  — lobe + domed upper body, no bottom ring
        ring_only()          — thin bottom ring, print separately & glue
        elna_single_cam()    — full assembly for preview/reference (unchanged API)

  Fixed geometry:
    - body height, central hole, lower counterbore/cone,
      transport slot, top dome style.

  Variable per cam:
    - lower functional cam edge (profile_points),
    - number text,
    - stitch pictogram (icon_points).

  Print workflow:
    1. Render cam_XX.scad → export cam_XX_body.stl  (use base_body_no_ring)
    2. Render cam_XX_ring.scad (or use ring_only module) → cam_XX_ring.stl
    3. Print both, glue ring to body bottom with superglue.

  License: GPL-3.0-or-later.
*/

$fn = 128;

// ── Fixed dimensions ────────────────────────────────────────────────────
overall_r        = 21.8200;  // max functional lobe radius
body_r           = 18.5500;  // upper body / base lobe radius
total_h          = 7.3080;   // total disc height
body_top_h       = 6.9990;   // height to top surface start
label_h          = 0.3090;   // raised marking height above top

lobe_h           = 4.4990;   // lower functional lobe height

// Dome parameters (v2 — lekko wypukły wierzch)
dome_crown       = 1.5000;   // max dome height at centre above body_top_h
// Computed sphere radius for given crown and body_r:
// r_sphere = (body_r^2 + dome_crown^2) / (2*dome_crown)
dome_r_sphere    = (body_r*body_r + dome_crown*dome_crown) / (2*dome_crown);
dome_base_z      = body_top_h - (dome_r_sphere - dome_crown);

// Bottom ring / rant (v2 — separate element)
ring_h           = 1.2000;   // ring height (matches lower part of lobe)
ring_r_outer     = overall_r; // outer matches max lobe radius
ring_r_inner     = body_r;    // inner = body cylinder radius
// The ring sits at z=0 (very bottom of disc)

// Central hole and counterbore
center_hole_r    = 8.2500;
counterbore_r    = 9.5000;
counterbore_h    = 1.5000;
cone_h           = 1.5000;

// Transport / locating slot
transport_w      = 3.0000;
transport_len    = 4.1000;
transport_depth  = 5.5000;
transport_gap    = 1.0000;

cut_eps          = 0.08;

// ── Helper modules ──────────────────────────────────────────────────────

module annulus(h, ro, ri) {
    difference() {
        cylinder(h=h, r=ro);
        translate([0, 0, -cut_eps]) cylinder(h=h+2*cut_eps, r=ri);
    }
}

// Dome cap — sphere-segment above body_top_h
module dome_cap() {
    intersection() {
        translate([0, 0, dome_base_z])
            sphere(r=dome_r_sphere, $fn=128);
        // Only the part above body_top_h and within body_r
        translate([0, 0, body_top_h])
            cylinder(h=dome_crown + cut_eps, r=body_r);
    }
}

// ── Structural body (no ring) ───────────────────────────────────────────

module base_body_no_ring(profile_points) {
    union() {
        // Lower functional cam lobe — only this outer edge changes per cam.
        // Starts at z=ring_h so the ring slot is clean.
        translate([0, 0, ring_h])
            linear_extrude(height=lobe_h - ring_h)
                polygon(points=profile_points);

        // Upper circular body — preserves Elna-style disc.
        cylinder(h=body_top_h, r=body_r);

        // Dome top surface (v2)
        dome_cap();

        // Very thin reference rim at top edge.
        translate([0, 0, body_top_h - 0.22])
            annulus(h=0.22, ro=body_r+0.10, ri=body_r-0.45);

        // Inner raised ring around main hole.
        translate([0, 0, body_top_h - 0.45])
            annulus(h=0.45, ro=center_hole_r+2.05, ri=center_hole_r+0.35);
    }
}

// ── Bottom ring (rant) — separate printable element ─────────────────────

module ring_only(profile_points) {
    // Ring follows the outer functional lobe profile at bottom
    // Inner wall is the body_r cylinder
    difference() {
        union() {
            // Outer ring shell follows lobe profile
            linear_extrude(height=ring_h)
                polygon(points=profile_points);
            // Inner fill to body_r (so it glues flush)
            cylinder(h=ring_h, r=body_r);
        }
        // Hollow center (shaft hole)
        translate([0, 0, -cut_eps])
            cylinder(h=ring_h + 2*cut_eps, r=center_hole_r);
        // Lower widened bore
        translate([0, 0, -cut_eps])
            cylinder(h=counterbore_h + cut_eps, r=counterbore_r);
        // Taper from bore to hole
        translate([0, 0, counterbore_h - cut_eps])
            cylinder(h=cone_h, r1=counterbore_r, r2=center_hole_r);
        // Transport slot passes through ring too
        translate([0, counterbore_r + transport_gap + transport_len/2,
                   transport_depth/2 - cut_eps])
            cube(size=[transport_w, transport_len, transport_depth], center=true);
    }
}

// ── Shared hole/slot cutter ─────────────────────────────────────────────

module holes_and_slots() {
    // Main shaft hole
    translate([0, 0, -cut_eps])
        cylinder(h=total_h + dome_crown + 2*cut_eps, r=center_hole_r);

    // Lower widened bore
    translate([0, 0, -cut_eps])
        cylinder(h=counterbore_h + cut_eps, r=counterbore_r);

    // Taper from bore to hole
    translate([0, 0, counterbore_h - cut_eps])
        cylinder(h=cone_h, r1=counterbore_r, r2=center_hole_r);

    // Transport slot
    translate([0, counterbore_r + transport_gap + transport_len/2,
               transport_depth/2 - cut_eps])
        cube(size=[transport_w, transport_len, transport_depth], center=true);
}

// ── Top markings ────────────────────────────────────────────────────────

module raised_stroke_path(points=[[0,0],[1,1]], pos=[0,0], scale_xy=[1,1],
                          width=0.46, height=label_h) {
    module node(p) {
        translate([pos[0] + p[0]*scale_xy[0], pos[1] + p[1]*scale_xy[1],
                   body_top_h + dome_crown])
            cylinder(h=height, r=width/2, $fn=18);
    }
    for (i=[0:len(points)-2]) {
        hull() { node(points[i]); node(points[i+1]); }
    }
}

module top_markings(number_text="03", icon_points=[[0,0],[1,1]]) {
    top_z = body_top_h + dome_crown;

    // Number badge
    translate([11.55, -7.25, top_z])
        annulus(h=label_h, ro=2.95, ri=2.35);
    translate([11.55, -7.25, top_z])
        linear_extrude(height=label_h)
            text(number_text, size=3.25, halign="center", valign="center",
                 font="Liberation Sans:style=Bold");

    // Blank badge opposite side
    translate([-11.80, -7.25, top_z])
        annulus(h=label_h, ro=2.80, ri=2.20);

    // Stitch pictogram
    raised_stroke_path(points=icon_points, pos=[0,-11.65],
                       scale_xy=[7.50, 2.45], width=0.44, height=label_h);

    // "SWISS" mark
    translate([-14.35, 0.80, top_z])
        rotate([0, 0, 90])
            linear_extrude(height=label_h)
                text("SWISS", size=2.1, halign="center", valign="center",
                     font="Liberation Sans:style=Bold");

    // "MADE" mark
    translate([0.0, -15.15, top_z])
        linear_extrude(height=label_h)
            text("MADE", size=2.0, halign="center", valign="center",
                 font="Liberation Sans:style=Bold");

    // Small pips along lower arc
    for (a=[208:10:332]) {
        rotate([0, 0, a])
            translate([body_r - 0.55, 0, top_z])
                cube([0.62, 0.34, label_h], center=true);
    }
}

// ── Public API ───────────────────────────────────────────────────────────

// Full assembly — for OpenSCAD preview and reference rendering
module elna_single_cam(profile_points, icon_points, number_text="03") {
    difference() {
        union() {
            base_body_no_ring(profile_points=profile_points);
            ring_only(profile_points=profile_points);
            top_markings(number_text=number_text, icon_points=icon_points);
        }
        holes_and_slots();
    }
}

// Body only — print this part (glue ring to bottom)
module elna_cam_body(profile_points, icon_points, number_text="03") {
    difference() {
        union() {
            base_body_no_ring(profile_points=profile_points);
            top_markings(number_text=number_text, icon_points=icon_points);
        }
        holes_and_slots();
    }
}

// Ring only — print this separately, glue to cam body bottom
module elna_cam_ring(profile_points) {
    ring_only(profile_points=profile_points);
}
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

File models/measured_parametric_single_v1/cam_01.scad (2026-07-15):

/*
  Elna Supermatic cam 01
  Name: Elastic multi-step
  Status: candidate

  Generated from measured parametric base v2.
  Surface mode: smooth
*/

include <_elna_measured_common.scad>;

profile_points = [
        [0.0000, 19.0950],
        [0.6671, 19.1020],
        [1.3371, 19.1212],
        [2.0124, 19.1468],
        [2.6942, 19.1702],
        [3.3821, 19.1806],
        [4.0739, 19.1662],
        [4.7660, 19.1155],
        [5.4535, 19.0187],
        [6.1307, 18.8683],
        [6.7918, 18.6604],
        [7.4479, 18.4343],
        [8.1151, 18.2268],
        [8.7938, 18.0300],
        [9.4819, 17.8328],
        [10.1742, 17.6223],
        [10.8634, 17.3850],
        [11.5400, 17.1087],
        [12.1938, 16.7833],
        [12.8150, 16.4024],
        [13.3951, 15.9636],
        [13.9565, 15.5003],
        [14.5266, 15.0427],
        [15.1034, 14.5852],
        [15.6823, 14.1204],
        [16.2558, 13.6403],
        [16.8149, 13.1372],
        [17.3492, 12.6049],
        [17.8485, 12.0389],
        [18.3037, 11.4374],
        [18.7079, 10.8010],
        [19.0569, 10.1328],
        [19.3503, 9.4378],
        [19.5907, 8.7224],
        [19.7846, 7.9935],
        [19.9407, 7.2578],
        [20.0698, 6.5211],
        [20.1829, 5.7874],
        [20.2907, 5.0590],
        [20.4019, 4.3366],
        [20.5224, 3.6187],
        [20.6124, 2.8969],
        [20.6317, 2.1685],
        [20.5865, 1.4396],
        [20.4876, 0.7154],
        [20.3485, 0.0000],
        [20.1846, -0.7049],
        [20.0113, -1.3993],
        [19.8424, -2.0855],
        [19.6885, -2.7670],
        [19.5563, -3.4483],
        [19.4058, -4.1248],
        [19.1974, -4.7865],
        [18.9376, -5.4303],
        [18.6354, -6.0550],
        [18.3019, -6.6614],
        [17.9490, -7.2519],
        [17.5878, -7.8306],
        [17.2280, -8.4026],
        [16.8764, -8.9733],
        [16.5368, -9.5475],
        [16.2093, -10.1287],
        [15.8909, -10.7185],
        [15.5754, -11.3162],
        [15.2548, -11.9184],
        [14.9199, -12.5193],
        [14.5615, -13.1112],
        [14.1715, -13.6853],
        [13.7439, -14.2322],
        [13.2751, -14.7435],
        [12.7645, -15.2121],
        [12.2406, -15.6672],
        [11.7273, -16.1412],
        [11.2175, -16.6307],
        [10.7027, -17.1280],
        [10.1742, -17.6223],
        [9.6242, -18.1005],
        [9.0466, -18.5482],
        [8.4379, -18.9518],
        [7.7974, -19.2993],
        [7.1274, -19.5823],
        [6.4454, -19.8368],
        [5.7641, -20.1018],
        [5.0795, -20.3726],
        [4.3875, -20.6415],
        [3.6849, -20.8981],
        [2.9697, -21.1307],
        [2.2416, -21.3273],
        [1.5018, -21.4767],
        [0.7532, -21.5702],
        [0.0000, -21.6020],
        [-0.7532, -21.5702],
        [-1.5018, -21.4767],
        [-2.2416, -21.3273],
        [-2.9697, -21.1307],
        [-3.6849, -20.8981],
        [-4.3875, -20.6415],
        [-5.0795, -20.3726],
        [-5.7641, -20.1018],
        [-6.4454, -19.8368],
        [-7.1274, -19.5823],
        [-7.7974, -19.2993],
        [-8.4379, -18.9518],
        [-9.0466, -18.5482],
        [-9.6242, -18.1005],
        [-10.1743, -17.6223],
        [-10.7027, -17.1280],
        [-11.2175, -16.6307],
        [-11.7273, -16.1412],
        [-12.2406, -15.6672],
        [-12.7645, -15.2121],
        [-13.2751, -14.7435],
        [-13.7439, -14.2322],
        [-14.1715, -13.6853],
        [-14.5615, -13.1112],
        [-14.9199, -12.5193],
        [-15.2548, -11.9184],
        [-15.5754, -11.3162],
        [-15.8909, -10.7185],
        [-16.2093, -10.1287],
        [-16.5368, -9.5475],
        [-16.8764, -8.9733],
        [-17.2280, -8.4026],
        [-17.5878, -7.8306],
        [-17.9490, -7.2519],
        [-18.3019, -6.6614],
        [-18.6354, -6.0550],
        [-18.9376, -5.4303],
        [-19.1974, -4.7865],
        [-19.4058, -4.1248],
        [-19.5563, -3.4483],
        [-19.6885, -2.7670],
        [-19.8424, -2.0855],
        [-20.0113, -1.3993],
        [-20.1846, -0.7049],
        [-20.3485, -0.0000],
        [-20.4876, 0.7154],
        [-20.5865, 1.4396],
        [-20.6317, 2.1685],
        [-20.6124, 2.8969],
        [-20.5224, 3.6187],
        [-20.4019, 4.3366],
        [-20.2907, 5.0590],
        [-20.1829, 5.7874],
        [-20.0698, 6.5211],
        [-19.9407, 7.2578],
        [-19.7846, 7.9935],
        [-19.5907, 8.7224],
        [-19.3503, 9.4378],
        [-19.0569, 10.1328],
        [-18.7079, 10.8010],
        [-18.3037, 11.4374],
        [-17.8485, 12.0389],
        [-17.3492, 12.6049],
        [-16.8149, 13.1372],
        [-16.2558, 13.6403],
        [-15.6823, 14.1204],
        [-15.1034, 14.5852],
        [-14.5266, 15.0427],
        [-13.9565, 15.5003],
        [-13.3951, 15.9636],
        [-12.8150, 16.4024],
        [-12.1938, 16.7833],
        [-11.5400, 17.1087],
        [-10.8634, 17.3850],
        [-10.1743, 17.6223],
        [-9.4819, 17.8328],
        [-8.7938, 18.0300],
        [-8.1151, 18.2268],
        [-7.4479, 18.4343],
        [-6.7918, 18.6604],
        [-6.1307, 18.8683],
        [-5.4535, 19.0187],
        [-4.7660, 19.1155],
        [-4.0739, 19.1662],
        [-3.3821, 19.1806],
        [-2.6942, 19.1702],
        [-2.0124, 19.1468],
        [-1.3371, 19.1212],
        [-0.6671, 19.1020]
];

icon_points = [[-1.000,0.180], [-0.820,0.180], [-0.820,0.360], [-0.640,0.360], [-0.640,0.560], [-0.460,0.560], [-0.460,0.740], [-0.280,0.740], [-0.280,0.560], [-0.100,0.560], [-0.100,0.360], [0.080,0.360], [0.080,0.180], [0.260,0.180], [0.260,0.360], [0.440,0.360], [0.440,0.560], [0.620,0.560], [0.620,0.740], [0.800,0.740], [1.000,0.740]];

elna_single_cam(profile_points=profile_points, icon_points=icon_points, number_text="01");

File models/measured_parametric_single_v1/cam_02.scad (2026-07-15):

/*
  Elna Supermatic cam 02
  Name: Serpentine
  Status: candidate

  Generated from measured parametric base v2.
  Surface mode: smooth
*/

include <_elna_measured_common.scad>;

profile_points = [
        [0.0000, 20.1850],
        [0.7051, 20.1914],
        [1.4131, 20.2085],
        [2.1263, 20.2308],
        [2.8459, 20.2496],
        [3.5713, 20.2540],
        [4.3005, 20.2324],
        [5.0297, 20.1732],
        [5.7540, 20.0665],
        [6.4675, 19.9050],
        [7.1646, 19.6847],
        [7.8533, 19.4375],
        [8.5457, 19.1940],
        [9.2421, 18.9491],
        [9.9406, 18.6955],
        [10.6375, 18.4247],
        [11.3276, 18.1279],
        [12.0043, 17.7971],
        [12.6606, 17.4259],
        [13.2897, 17.0100],
        [13.8855, 16.5481],
        [14.4563, 16.0554],
        [15.0132, 15.5467],
        [15.5553, 15.0216],
        [16.0814, 14.4798],
        [16.5898, 13.9205],
        [17.0788, 13.3434],
        [17.5464, 12.7482],
        [17.9906, 12.1348],
        [18.4097, 11.5037],
        [18.8023, 10.8555],
        [19.1532, 10.1839],
        [19.4482, 9.4855],
        [19.6903, 8.7667],
        [19.8857, 8.0343],
        [20.0432, 7.2951],
        [20.1734, 6.5547],
        [20.2877, 5.8174],
        [20.3965, 5.0854],
        [20.5085, 4.3592],
        [20.6298, 3.6376],
        [20.7256, 2.9128],
        [20.7608, 2.1820],
        [20.7401, 1.4503],
        [20.6718, 0.7219],
        [20.5665, 0.0000],
        [20.4362, -0.7136],
        [20.2927, -1.4190],
        [20.1469, -2.1175],
        [20.0071, -2.8118],
        [19.8783, -3.5051],
        [19.7256, -4.1928],
        [19.5147, -4.8656],
        [19.2519, -5.5204],
        [18.9464, -6.1560],
        [18.6092, -6.7732],
        [18.2522, -7.3744],
        [17.8865, -7.9636],
        [17.5219, -8.5460],
        [17.1651, -9.1268],
        [16.8199, -9.7110],
        [16.4572, -10.2836],
        [16.0498, -10.8257],
        [15.6037, -11.3367],
        [15.1267, -11.8183],
        [14.6276, -12.2740],
        [14.1153, -12.7094],
        [13.5975, -13.1310],
        [13.0807, -13.5455],
        [12.5690, -13.9592],
        [12.0638, -14.3771],
        [11.5531, -14.7873],
        [11.0254, -15.1752],
        [10.4824, -15.5408],
        [9.9256, -15.8842],
        [9.3567, -16.2064],
        [8.7775, -16.5082],
        [8.1894, -16.7908],
        [7.5935, -17.0554],
        [6.9908, -17.3028],
        [6.3818, -17.5337],
        [5.7717, -17.7635],
        [5.1632, -18.0062],
        [4.5521, -18.2573],
        [3.9342, -18.5091],
        [3.3063, -18.7512],
        [2.6663, -18.9719],
        [2.0137, -19.1592],
        [1.3497, -19.3020],
        [0.6772, -19.3915],
        [0.0000, -19.4220],
        [-0.6785, -19.4288],
        [-1.3599, -19.4474],
        [-2.0466, -19.4720],
        [-2.7397, -19.4940],
        [-3.4388, -19.5026],
        [-4.1419, -19.4861],
        [-4.8451, -19.4328],
        [-5.5437, -19.3330],
        [-6.2317, -19.1793],
        [-6.9037, -18.9677],
        [-7.5684, -18.7325],
        [-8.2396, -18.5065],
        [-8.9175, -18.2835],
        [-9.6000, -18.0551],
        [-10.2833, -17.8111],
        [-10.9611, -17.5414],
        [-11.6260, -17.2363],
        [-12.2701, -16.8883],
        [-12.8854, -16.4925],
        [-13.4651, -16.0471],
        [-14.0277, -15.5793],
        [-14.5951, -15.1137],
        [-15.1657, -14.6453],
        [-15.7353, -14.1681],
        [-16.2976, -13.6753],
        [-16.8446, -13.1604],
        [-17.3673, -12.6181],
        [-17.8571, -12.0448],
        [-18.3060, -11.4388],
        [-18.7079, -10.8010],
        [-19.0758, -10.1428],
        [-19.4251, -9.4743],
        [-19.7549, -8.7955],
        [-20.0639, -8.1064],
        [-20.3505, -7.4070],
        [-20.6126, -6.6974],
        [-20.8484, -5.9782],
        [-21.0560, -5.2498],
        [-21.2340, -4.5134],
        [-21.3812, -3.7701],
        [-21.4812, -3.0190],
        [-21.5196, -2.2618],
        [-21.5012, -1.5035],
        [-21.4343, -0.7485],
        [-21.3295, -0.0000],
        [-21.1987, 0.7403],
        [-21.0538, 1.4722],
        [-20.9057, 2.1973],
        [-20.7626, 2.9180],
        [-20.6298, 3.6376],
        [-20.4720, 4.3515],
        [-20.2551, 5.0502],
        [-19.9853, 5.7307],
        [-19.6720, 6.3918],
        [-19.3262, 7.0342],
        [-18.9596, 7.6602],
        [-18.5836, 8.2739],
        [-18.2076, 8.8805],
        [-17.8388, 9.4850],
        [-17.4807, 10.0925],
        [-17.1020, 10.6865],
        [-16.6737, 11.2466],
        [-16.2028, 11.7720],
        [-15.6983, 12.2648],
        [-15.1704, 12.7294],
        [-14.6293, 13.1722],
        [-14.0841, 13.6009],
        [-13.5423, 14.0234],
        [-13.0083, 14.4472],
        [-12.4842, 14.8781],
        [-11.9475, 15.2921],
        [-11.3793, 15.6622],
        [-10.7853, 15.9898],
        [-10.1724, 16.2792],
        [-9.5475, 16.5368],
        [-8.9171, 16.7707],
        [-8.2864, 16.9897],
        [-7.6590, 17.2025],
        [-7.0366, 17.4162],
        [-6.4190, 17.6362],
        [-5.8103, 17.8824],
        [-5.2105, 18.1710],
        [-4.6110, 18.4939],
        [-4.0039, 18.8367],
        [-3.3821, 19.1806],
        [-2.7411, 19.5038],
        [-2.0794, 19.7840],
        [-1.3986, 20.0008],
        [-0.7032, 20.1380]
];

icon_points = [[-1.000,0.500], [-0.956,0.599], [-0.911,0.691], [-0.867,0.768], [-0.822,0.824], [-0.778,0.855], [-0.733,0.858], [-0.689,0.834], [-0.644,0.784], [-0.600,0.712], [-0.556,0.623], [-0.511,0.525], [-0.467,0.425], [-0.422,0.331], [-0.378,0.250], [-0.333,0.188], [-0.289,0.151], [-0.244,0.140], [-0.200,0.158], [-0.156,0.202], [-0.111,0.269], [-0.067,0.354], [-0.022,0.450], [0.022,0.550], [0.067,0.646], [0.111,0.731], [0.156,0.798], [0.200,0.842], [0.244,0.860], [0.289,0.849], [0.333,0.812], [0.378,0.750], [0.422,0.669], [0.467,0.575], [0.511,0.475], [0.556,0.377], [0.600,0.288], [0.644,0.216], [0.689,0.166], [0.733,0.142], [0.778,0.145], [0.822,0.176], [0.867,0.232], [0.911,0.309], [0.956,0.401], [1.000,0.500]];

elna_single_cam(profile_points=profile_points, icon_points=icon_points, number_text="02");

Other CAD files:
stls/cam_19_body.stl
stls/cam_01_body.stl
stls/cam_09_body.stl
stls/cam_26_body.stl
stls/cam_25_body.stl
models/measured_parametric_single_v1/cam_01_body.scad
models/measured_parametric_single_v1/cam_02_body.scad
models/measured_parametric_single_v1/cam_03.scad
models/measured_parametric_single_v1/cam_03_body.scad
models/measured_parametric_single_v1/cam_04.scad
models/measured_parametric_single_v1/cam_04_body.scad
models/measured_parametric_single_v1/cam_05.scad
models/measured_parametric_single_v1/cam_05_body.scad
models/measured_parametric_single_v1/cam_06.scad
models/measured_parametric_single_v1/cam_06_body.scad
models/measured_parametric_single_v1/cam_07.scad
models/measured_parametric_single_v1/cam_07_body.scad
models/measured_parametric_single_v1/cam_08.scad
models/measured_parametric_single_v1/cam_08_body.scad
models/measured_parametric_single_v1/cam_09.scad
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

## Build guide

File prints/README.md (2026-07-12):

# Print tests

Use this folder for notes and photos from physical print tests.

Recommended file names:

```text
cam_03_print_test.md
cam_13_print_test.md
```

Do not mark a cam as verified until it has passed a slow hand-wheel test in the machine.

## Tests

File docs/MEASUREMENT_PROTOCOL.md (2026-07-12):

# Measurement and photo protocol

To improve or verify a cam profile, provide:

## Best case

- top-down photo of the cam,
- bottom photo,
- visible cam number,
- visible stitch pictogram,
- no strong perspective,
- known scale, e.g. caliper or ruler,
- ideally 1500 px or more across the disc.

## Minimum useful photo

- full outer cam edge visible,
- central hole visible,
- locating/transport slot visible,
- cam number visible.

## Verification checklist

A model can be marked as verified only after:

1. profile extracted or measured from a real cam,
2. OpenSCAD model compared visually,
3. printed test part fits without force,
4. machine rotates by hand safely,
5. stitch output matches the expected pattern.

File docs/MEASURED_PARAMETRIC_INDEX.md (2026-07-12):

# Measured parametric cam index

This set uses dimensions read from the uploaded STL/SCAD files.

## Status

- `uploaded-stl/scad-reference` — cam 03 reference.
- `source-profile` — known 18-position profile from existing OpenSCAD source models.
- `candidate` — base and style are measured, but functional edge still needs photo/STL verification.

| Cam | Name | Status | File |
|---:|---|---|---|
| 01 | Elastic multi-step | candidate | `models/measured_parametric_single_v1/cam_01.scad` |
| 02 | Serpentine | candidate | `models/measured_parametric_single_v1/cam_02.scad` |
| 03 | Zigzag reference | uploaded-stl/scad-reference | `models/measured_parametric_single_v1/cam_03.scad` |
| 04 | Long scallop | candidate | `models/measured_parametric_single_v1/cam_04.scad` |
| 05 | Scallop | candidate | `models/measured_parametric_single_v1/cam_05.scad` |
| 06 | Wide zigzag | candidate | `models/measured_parametric_single_v1/cam_06.scad` |
| 07 | Decorative zigzag | candidate | `models/measured_parametric_single_v1/cam_07.scad` |
| 08 | Slanted bars | candidate | `models/measured_parametric_single_v1/cam_08.scad` |
| 09 | W stitch | candidate | `models/measured_parametric_single_v1/cam_09.scad` |
| 10 | Blind hem | candidate | `models/measured_parametric_single_v1/cam_10.scad` |
| 11 | Arrows | candidate | `models/measured_parametric_single_v1/cam_11.scad` |
| 12 | Spindle | candidate | `models/measured_parametric_single_v1/cam_12.scad` |
| 13 | Source profile 13 | source-profile | `models/measured_parametric_single_v1/cam_13.scad` |
| 14 | Loop wave | candidate | `models/measured_parametric_single_v1/cam_14.scad` |
| 15 | Triangle | candidate | `models/measured_parametric_single_v1/cam_15.scad` |
| 16 | Source profile 16 | source-profile | `models/measured_parametric_single_v1/cam_16.scad` |
| 17 | Round pulses | candidate | `models/measured_parametric_single_v1/cam_17.scad` |
| 18 | Deep scallop | candidate | `models/measured_parametric_single_v1/cam_18.scad` |
| 19 | Dense zigzag | candidate | `models/measured_parametric_single_v1/cam_19.scad` |
| 20 | Source profile 20 | source-profile | `models/measured_parametric_single_v1/cam_20.scad` |
| 21 | Stair zigzag | candidate | `models/measured_parametric_single_v1/cam_21.scad` |
| 22 | Small lobes | candidate | `models/measured_parametric_single_v1/cam_22.scad` |
| 23 | Sharp triangles | candidate | `models/measured_parametric_single_v1/cam_23.scad` |
| 24 | Small scallop | candidate | `models/measured_parametric_single_v1/cam_24.scad` |
| 25 | Large sine wave | candidate | `models/measured_parametric_single_v1/cam_25.scad` |
| 26 | Wave variant | candidate | `models/measured_parametric_single_v1/cam_26.scad` |
| 27 | Irregular pulse | candidate | `models/measured_parametric_single_v1/cam_27.scad` |
| 28 | Vertical ticks | candidate | `models/measured_parametric_single_v1/cam_28.scad` |
| 29 | Comb alternate | candidate | `models/measured_parametric_single_v1/cam_29.scad` |
| 30 | Uneven wave | candidate | `models/measured_parametric_single_v1/cam_30.scad` |
| 31 | Block sawtooth | candidate | `models/measured_parametric_single_v1/cam_31.scad` |
| 32 | Slanted bars | candidate | `models/measured_parametric_single_v1/cam_32.scad` |
| 33 | Source profile 33 | source-profile | `models/measured_parametric_single_v1/cam_33.scad` |
| 34 | Extra decorative | candidate | `models/measured_parametric_single_v1/cam_34.scad` |

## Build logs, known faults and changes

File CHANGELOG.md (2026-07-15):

# Changelog

All notable changes to this project will be documented in this file.

The format follows [Keep a Changelog](https://keepachangelog.com/en/1.0.0/).
This project uses [Semantic Versioning](https://semver.org/).

---

## [Unreleased]

### Planned
- Physical test results for candidate cams
- Top-down reference photos for unverified cams
- Corrected outer profiles based on physical measurements

---

## [0.1.0] — 2026-07-15

### Added
- Measured parametric Elna Supermatic single cam base (`_elna_measured_common.scad`)
- Generated SCAD files for cams 01–34 in `models/measured_parametric_single_v1/`
- Profile JSON files for all 34 cams in `profiles/`
- Dimension documentation from uploaded STL/SCAD reference files (`docs/DIMENSIONS_FROM_UPLOADED_FILES.md`)
- Verification status system: `uploaded-stl/scad-reference`, `source-profile`, `candidate`
- Grounded models: cam 03 (STL/SCAD reference), cams 13, 16, 20, 33 (known 18-position profiles)
- Validation script for profile JSON files (`tools/`)
- Measurement protocol documentation (`docs/MEASUREMENT_PROTOCOL.md`)
- Status tracking document (`docs/STATUS.md`)
- `.gitignore` to prevent accidental commits of generated STL files

### Design decisions
- Body geometry is fixed and shared via `_elna_measured_common.scad`
- Only the functional cam edge, cam number, and stitch pictogram change per cam
- This approach replaced an earlier failed attempt to edit frozen mesh SCAD files (Patch 008)

[Unreleased]: https://github.com/qbarteczek/elna-supermatic-cams/compare/v0.1.0...HEAD
[0.1.0]: https://github.com/qbarteczek/elna-supermatic-cams/releases/tag/v0.1.0

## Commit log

2026-07-15 docs: improve README, CONTRIBUTING, add CHANGELOG, .gitignore and CI
    - README: rewrite with What is Elna Supermatic section, prerequisites,
    quick start, key dimensions table, complete file structure, safety warning,
    link to docs/STATUS.md and CONTRIBUTING.md
    - CONTRIBUTING: add full instructions for adding a verified cam, status
    table, pull request checklist, and code style guide
    - CHANGELOG.md: add Keep a Changelog format file (replaces incomplete
    RELEASE_NOTES.md, which is kept for reference)
    - .gitignore: prevent committing generated STL/AMF/3MF files, Python
    cache, OS files, and editor temp files
    - docs/PATCH_008_NOTES.md: move README_PATCH_008.md to docs/ as
    historical refer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
2026-07-15 feat: updated cam geometry with separate ring and top dome, pre-rendered 34 STLs
    [_elna_measured_common.scad, cam_01.scad, cam_01.stl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]
2026-07-22 feat: generate printable body and ring STL models for V2 geometry (no supports needed)
    [cam_01_body.scad, cam_01_body.stl, cam_01_ring.scad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]
2026-07-22 docs: add clear step-by-step 3D printing, assembly and machine mounting guide in EN/PL
2026-07-22 feat: add universal_ring.stl fitting all 34 cams and update README documentation
    [_elna_measured_common.scad, universal_ring.scad, universal_ring.stl]
2026-07-22 refactor: remove redundant individual ring files; use universal_ring.stl exclusively for all cams
    [cam_01_ring.scad, cam_01_ring.stl, cam_02_ring.scad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]
2026-09-10 feat: in-browser real-time 3D cam generator with direct STL export and GitHub Pages app
    [elna_cam_generator.scad]
2026-09-10 feat: realistic 3D preview with official STL models, domed top, keyway, and part switchers
2026-09-10 feat(editor): add direct 34-stitch selector dropdown, prev/next buttons, and load-by-number in 18-step editor
2026-10-23 fix: markings sit on the cam top, flat top like reference, watertight STL with slot
    - markings/pictograms no longer float above the dome (were 26 loose shells per STL);
    trimmed to the real top surface, flat top 7.308 mm like the reference (dome optional)
    - body + universal ring add up to the assembly; lobe starts at 1.2 mm
    - stepped profiles centred on the transport slot (were 10 deg off), dwells are arcs
    - cam 33 profile fixed (16 -> 18 values)
    - browser: watertight STL export with transport slot, markings texture on the top face,
    same profile math as OpenSCAD, catalogue STL only for unchanged presets, 11 pictograms
    - one source of truth (profiles JSON + generate_cam.py), regenerate_sca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
2026-10-23 fix: transport slot roof at exactly 5.5 mm (was 5.42); add tools/verify_stls.py
    Slot cutter was shifted down by cut_eps. All 69 STL re-rendered; independent check
    (tools/verify_stls.py by the second session): 34 cams checked, 0 problems.
